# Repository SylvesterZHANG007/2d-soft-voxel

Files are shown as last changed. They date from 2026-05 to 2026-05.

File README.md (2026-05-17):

# 2D Soft Voxel Modular Robot

**[📖 Open Interactive Guide →](https://sylvesterzhang007.github.io/2d-soft-voxel/)**

A 2D soft voxel modular robot system driven by servo motors and gear-rack mechanisms. Each voxel module can actively extend and retract, enabling coordinated multi-module locomotion patterns.

## Repository Structure

```
2d soft voxel/
├── code/                          # Arduino firmware
│   ├── 16_module/                 # 16-servo coordinated sinusoidal motion
│   └── certain_angle/             # Single-servo angle calibration utility
├── hardware model/                # Current SolidWorks design files (v6)
│   ├── soft_voxel_newest version (v6)/   # Latest full voxel assembly
│   ├── battery and board assem/          # Battery housing + servo driver board mount
│   └── cover molding/                    # Cover parts with print-ready STLs
├── print/                         # STL / 3MF files ready for 3D printing (current version)
├── figure and video/              # Photos and demo videos of the hardware
└── previous hardware model (OLD)/ # Design history: v1 → v5 (reference only)
    ├── v2/ … v5/
    └── (loose files)
```

## Hardware

### Key Components
| Component | Description |
|---|---|
| Servo | AGFRC A06CLS V2 (micro coreless servo) |
| PWM Driver | 815 16-Channel Servo Driver (PCA9685-based, I²C address `0x41`) |
| Gear System | Metal gear rack — 20° pressure angle (McMaster-Carr `3757N35`) |
| Microcontroller | Arduino Nano ESP32 |

### 3D Printing (current version — v6)
All print-ready STL/3MF files are in `print/`. Key parts:

| File | Description |
|---|---|
| `entire cover.STL` / `Mirrorentire cover.STL` | Left/right voxel outer covers |
| `gear rack_curve.STL` / `Mirrorgear rack_curve.STL` | Curved gear racks (mirrored pair) |
| `gear rack_curve_offset.STL` / `Mirrorgear rack_curve_offset.STL` | Offset gear racks (mirrored pair) |
| `gear back.STL` | Rear gear support |
| `servo_mount.STL` | Servo mounting bracket |
| `cover_mount.STL` | Cover attachment plate |
| `connector.STL` / `connector1.STL` | Inter-module connectors |
| `battery case.STL` / `battery cover.STL` / `battery switch cover.STL` | Battery enclosure |
| `board support1.STL` | PCB mounting support |
| `switch_v5.STL` | Power switch housing |

### Printing and Casting Materials

| Part Category | Material | Notes |
|---|---|---|
| Module main body (all structural parts) | Bambu Lab PLA Matte — Ivory White | Standard FDM print |
| All gear racks (`gear rack_curve`, `gear rack_curve_offset`, and mirrored variants) | Bambu Lab TPU 95A — Black | Flexible; improves gear mesh compliance and reduces noise |
| Connectors (`connector.STL`, `connector1.STL`) | Bambu Lab PLA — Glow Green | Easy visual identification between modules |
| Cover molding parts (`hardware model/cover molding/`) | Eco-Flex 10 (Smooth-On) | Cast molding — do not 3D print these parts |

**Casting Note:** The cover molding components are designed for silicone casting using Eco-Flex 10. Print the mold halves (`bottom.STL`, `up.STL` in `hardware model/cover molding/print/`) in PLA, mix and pour Eco-Flex 10 per the manufacturer's datasheet, and allow to cure fully before demolding.

### SolidWorks Source Files
`hardware model/soft_voxel_newest version (v6)/` contains the full parametric SolidWorks assembly (`all_assm_1.SLDASM`) and all constituent part files (`.SLDPRT`). Open `all_assm_1.SLDASM` in SolidWorks 2025.

## Software

### Dependencies
- [Adafruit PWM Servo Driver Library](https://github.com/adafruit/Adafruit-PWM-Servo-Driver-Library) — install via Arduino Library Manager

### `code/16_module` — Coordinated 16-Servo Motion
Controls all 16 servos through the PCA9685 driver with a sinusoidal gait:

| Parameter | Value | Description |
|---|---|---|
| `PWM_FREQ` | 333 Hz | Servo PWM frequency |
| `CENTER_ANGLE` | −45° | Center position of oscillation |
| `AMPLITUDE` | 45° | Peak deviation from center |
| `FREQUENCY` | 1.0 Hz | Oscillation frequency |

Each servo has a sign (`servoSign[]`) that determines whether it extends or retracts in phase with the wave, creating a coordinated locomotion pattern across the 4×4 grid of modules.

**Wiring:** Connect PCA9685 to the microcontroller's I²C pins (SDA/SCL). Board address is `0x41`.

### `code/certain_angle` — Single-Servo Calibration
Sets one servo (pin `A3`) to a fixed angle using high-resolution PWM (14-bit, 333 Hz). Useful for calibrating trim and verifying servo range before assembly.

| Parameter | Value |
|---|---|
| `TRIM_US` | 0.0 µs (adjust to correct arm offset) |
| `NEUTRAL_US` | 1520 µs |
| `MIN_US` / `MAX_US` | 500 / 2500 µs |

Open Serial Monitor at 115200 baud to see the computed pulse width for each set angle.

## Design History

Previous hardware iterations are preserved in `previous hardware model (OLD)/` for reference:

| Version | Notes |
|---|---|
| v1–v2 | Early gear-rack concepts |
| v3 | Refined gear geometry; separate servo mount introduced |
| v4 | Alternative gear set with plastic gears; magnet-based connectors explored |
| v5 | Near-final layout; battery + board assembly integrated |
| v6 *(current)* | Streamlined assembly, improved cover molding, mirrored rack geometry |

## Media

`figure and video/` contains reference photos (`extended.jpg`, `shrinked.jpg`) and a demo video (`single module move.MOV`) showing a single voxel extending and retracting.

## Module Calibration and Assembly Guide

This guide outlines the standardized protocol for calibrating the servo motors and assembling the individual modules for the **2d-soft-voxel** robot.

To ensure identical kinematics, predictable behavior, and structural consistency across all modules, you must follow the precise hardware and software separation workflow described below.

---

### Phase 1: Direct Microcontroller Calibration (No PCA9685 Required)

During this initial mechanical alignment and single-module assembly phase, **DO NOT** use the PCA9685 PWM driver board.

The calibration and initial testing of individual module servos must be performed by connecting the servo signal lines **directly** to the designated GPIO pins of the Arduino Nano ESP32.

* **Power Source:** Power the microcontroller solely via the computer's USB port. Do not connect any external power supplies yet.
* **Software Control:** At this stage, exclusively use the `certain_angle` script/function to command and calibrate the servos. Do not attempt to run complex multi-servo coordination codes yet.
* **Why this approach?** This isolates the system to minimal hardware and software dependencies, drastically reducing troubleshooting complexity and preventing configuration or I2C communication errors on the expansion board during structural alignment.

---

### Phase 2: Step-by-Step Calibration and Assembly

#### Step 1: Servo Initial Zeroing
Before integrating any servo motor into a module casing, its spline position must be precisely zeroed to avoid mechanical binding or restricted range of motion post-assembly.
1. Connect the target servo directly to the Arduino Nano ESP32.
2. Run the `certain_angle` script to command the servo to its baseline calibration position (set the target angle to **-90 degrees**).
3. Ensure the servo motor has fully reached, settled, and locked into this position before disconnecting the setup or moving to mechanical installation.

#### Step 2: Reference Deconstruction and Observation
If you are replicating an existing reference module or scaling up production, use a proven module as your visual anchor:
1. Take an existing, correctly operating reference module and carefully disassemble/deconstruct it.
2. Closely observe and document the exact **relative orientation and mounting alignment** between the servo horn (arm) and the servo body at the -90-degree baseline.
3. Note the precise spline tooth engagement to ensure the newly assembled modules do not suffer from a gear-tooth offset.

#### Step 3: Calibrated Module Assembly
With the servo zeroed and the reference alignment understood, proceed to physical fabrication:
1. Mate the new servo horn onto the newly calibrated servo shaft, carefully duplicating the relative angle observed during the reference deconstruction in Step 2.
2. **Ensure Internal Component Consistency**: During final structural fastening, double-check that the relative positions of all internal components and linkages across different modules are completely identical and uniform.
3. Securely tighten all mounting screws while maintaining this alignment to eliminate any mechanical backlash, rotational slop, or structural shifting.

---

### ⚠️ CRITICAL SAFETY WARNING: POWER SEQUENCE

> **STOP:** Do not proceed to full-system testing or connect the high-current battery source until **all individual modules** have been successfully calibrated, assembled, and verified using **ONLY USB power** (via the Arduino Nano ESP32).
>
> Always verify that the system logic, control commands, and individual servo movements function flawlessly under safe USB power limits before connecting the battery. Failure to strictly follow this power sequence can result in permanent damage to the microcontroller and surrounding electronics in the event of an undetected short circuit.

---

## License

This project is released for research and educational use. If you build on this design, a citation or acknowledgment is appreciated.

---

# 2D 软体体素模块化机器人（中文版）

**[📖 打开可视化指导页面 →](https://sylvesterzhang007.github.io/2d-soft-voxel/)**

基于舵机与齿轮齿条机构驱动的 2D 软体体素模块化机器人系统。每个体素模块可主动伸缩，实现多模块协同运动。

## 仓库结构

```
2d soft voxel/
├── code/                          # Arduino 固件
│   ├── 16_module/                 # 16 路舵机协同正弦运动
│   └── certain_angle/             # 单路舵机角度校准工具
├── hardware model/                # 当前 SolidWorks 设计文件（v6）
│   ├── soft_voxel_newest version (v6)/   # 最新完整体素装配体
│   ├── battery and board assem/          # 电池仓 + 舵机驱动板安装座
│   └── cover molding/                    # 外壳零件及可打印 STL
├── print/                         # 当前版本可直接 3D 打印的 STL / 3MF 文件
├── figure and video/              # 硬件照片与演示视频
└── previous hardware model (OLD)/ # 设计历史：v1 → v5（仅供参考）
    ├── v2/ … v5/
    └── （散装文件）
```

## 硬件

### 关键组件
| 组件 | 说明 |
|---|---|
| 舵机 | AGFRC A06CLS V2（微型无铁芯舵机） |
| PWM 驱动板 | 815 16 路舵机驱动器（基于 PCA9685，I²C 地址 `0x41`） |
| 齿轮系统 | 金属齿轮齿条——20° 压力角（McMaster-Carr `3757N35`） |
| 微控制器 | Arduino 兼容板（已测试 Teensy / Arduino Nano） |

### 3D 打印（当前版本——v6）
所有可打印的 STL/3MF 文件均位于 `print/` 目录。主要零件：

| 文件 | 说明 |
|---|---|
| `entire cover.STL` / `Mirrorentire cover.STL` | 体素左/右侧外壳 |
| `gear rack_curve.STL` / `Mirrorgear rack_curve.STL` | 曲线齿条（镜像对） |
| `gear rack_curve_offset.STL` / `Mirrorgear rack_curve_offset.STL` | 偏置曲线齿条（镜像对） |
| `gear back.STL` | 齿轮背板支撑 |
| `servo_mount.STL` | 舵机安装支架 |
| `cover_mount.STL` | 外壳固定板 |
| `connector.STL` / `connector1.STL` | 模块间连接件 |
| `battery case.STL` / `battery cover.STL` / `battery switch cover.STL` | 电池仓组件 |
| `board support1.STL` | PCB 安装支撑 |
| `switch_v5.STL` | 电源开关壳体 |

### 打印与浇筑材料

| 零件类别 | 材料 | 备注 |
|---|---|---|
| 模块主体（所有结构件） | Bambu Lab PLA Matte — 象牙白（Ivory White） | 标准 FDM 打印 |
| 所有齿条（`gear rack_curve`、`gear rack_curve_offset` 及镜像件） | Bambu Lab TPU 95A — 黑色（Black） | 柔性材料；改善齿轮啮合顺应性，降低噪音 |
| 连接件（`connector.STL`、`connector1.STL`） | Bambu Lab PLA — 荧光绿（Glow Green） | 便于各模块之间的视觉识别 |
| 外壳模具零件（`hardware model/cover molding/`） | Eco-Flex 10（Smooth-On） | 浇筑成型——此类零件不得 3D 打印 |

**浇筑说明：** 外壳覆盖层零件设计为使用 Eco-Flex 10 进行硅胶浇筑成型。先用 PLA 打印模具两半（`hardware model/cover molding/print/` 下的 `bottom.STL` 和 `up.STL`），按厂商数据手册混合并浇注 Eco-Flex 10，待其完全固化后再脱模。

### SolidWorks 源文件
`hardware model/soft_voxel_newest version (v6)/` 包含完整的参数化 SolidWorks 装配体（`all_assm_1.SLDASM`）及所有零件文件（`.SLDPRT`）。请使用 SolidWorks 2025 打开 `all_assm_1.SLDASM`。

## 软件

### 依赖库
- [Adafruit PWM Servo Driver Library](https://github.com/adafruit/Adafruit-PWM-Servo-Driver-Library) — 通过 Arduino Library Manager 安装

### `code/16_module` — 16 路舵机协同运动
通过 PCA9685 驱动板以正弦步态控制全部 16 路舵机：

| 参数 | 值 | 说明 |
|---|----|---|
| `PWM_FREQ` | 333 Hz | 舵机 PWM 频率 |
| `CENTER_ANGLE` | −45° | 振荡中心位置 |
| `AMPLITUDE` | 45° | 偏离中心的峰值幅度 |
| `FREQUENCY` | 1.0 Hz | 振荡频率 |

每路舵机有一个符号值（`servoSign[]`），决定其与波形同相伸出还是缩回，从而在 4×4 模块阵列中形成协同运动步态。

**接线：** 将 PCA9685 连接至微控制器的 I²C 引脚（SDA/SCL），板载地址为 `0x41`。

### `code/certain_angle` — 单路舵机校准
使用高分辨率 PWM（14 位，333 Hz）将引脚 `A3` 上的舵机设置到指定角度，用于装配前的行程校准和零位验证。

| 参数 | 值 |
|---|----|
| `TRIM_US` | 0.0 µs（可调整以修正摆臂偏差） |
| `NEUTRAL_US` | 1520 µs |
| `MIN_US` / `MAX_US` | 500 / 2500 µs |

以 115200 波特率打开串口监视器，即可查看每个设定角度对应的脉冲宽度。

## 设计历史

历次硬件迭代均保存在 `previous hardware model (OLD)/` 中，仅供参考：

| 版本 | 说明 |
|---|---|
| v1–v2 | 早期齿轮齿条概念验证 |
| v3 | 齿轮几何优化；引入独立舵机安装座 |
| v4 | 探索塑料齿轮方案；尝试磁性连接件 |
| v5 | 接近最终布局；集成电池与驱动板装配体 |
| v6 *（当前）* | 简化装配、改进外壳模具、采用镜像齿条几何 |

## 媒体资料

`figure and video/` 包含参考照片（`extended.jpg`、`shrinked.jpg`）及演示视频（`single module move.MOV`），展示单个体素模块的伸缩动作。

## 模块校准与装配指南

本指南规定了 **2d-soft-voxel** 机器人舵机校准与单模块装配的标准化流程。

为确保所有模块具备相同的运动学特性、可预测的行为和一致的结构，必须严格遵循以下硬件与软件分离工作流程。

---

### 阶段一：直接通过微控制器校准（无需 PCA9685）

在初始机械对准和单模块装配阶段，**禁止**使用 PCA9685 PWM 驱动板。

单模块舵机的校准与初步测试，必须将舵机信号线**直接**连接至 Arduino Nano ESP32 的指定 GPIO 引脚进行。

* **供电方式：** 仅通过计算机 USB 口为微控制器供电，暂勿接入任何外部电源。
* **软件控制：** 此阶段只使用 `certain_angle` 脚本/函数控制和校准舵机，暂勿运行复杂的多舵机协同代码。
* **原因：** 将系统隔离至最少的硬件和软件依赖，可大幅降低排障复杂度，并防止在结构对准阶段出现扩展板配置错误或 I2C 通信故障。

---

### 阶段二：逐步校准与装配

#### 步骤 1：舵机初始归零
在将舵机装入模块外壳之前，必须精确校准其花键位置，以避免装配后出现机械卡死或运动范围受限。
1. 将目标舵机直接连接至 Arduino Nano ESP32。
2. 运行 `certain_angle` 脚本，将舵机指令至基准校准位置（目标角度设为 **-90 度**）。
3. 确认舵机已完全到达、稳定并锁定在该位置后，再断开连接或进行机械安装。

#### 步骤 2：参考模块拆解与观察
若需复制现有参考模块或批量生产，以一个已验证正常的模块作为视觉基准：
1. 取一个运行正确的参考模块，仔细拆解。
2. 仔细观察并记录舵机摆臂（臂）与舵机本体在 -90 度基准位置时的**相对朝向和安装对准**关系。
3. 注意花键齿的精确啮合位置，确保新装配的模块不出现齿位偏移。

#### 步骤 3：校准后的模块装配
完成舵机归零和参考对准后，进行实物组装：
1. 将新舵机摆臂套入已校准的舵机轴，仔细复现步骤 2 中观察到的相对角度。
2. **确保内部零件一致性：** 最终紧固结构时，逐一核查各模块内部所有零件和连杆的相对位置完全相同、均匀一致。
3. 在保持对准的前提下拧紧所有安装螺钉，消除机械间隙、旋转松旷或结构偏移。

---

### ⚠️ 重要安全警告：供电顺序

> **停止：** 在**所有单模块**均通过 **Arduino Nano ESP32 的 USB 供电**完成校准、装配和验证之前，禁止进行整机测试或连接大电流电池。
>
> 连接电池前，务必先在 USB 安全电流限制下确认系统逻辑、控制指令及单路舵机动作均正常无误。若不严格遵守此供电顺序，一旦存在未发现的短路，将导致微控制器及周边电子元件永久损坏。
>
> *只有当所有的模块在仅仅通过 USB 给 Arduino Nano ESP32 供电调试好之后，才能去连接电池进行下一步。*

---

## 许可证

本项目供研究和教育用途开放使用。若您基于本设计进行二次开发，欢迎注明来源或致谢。

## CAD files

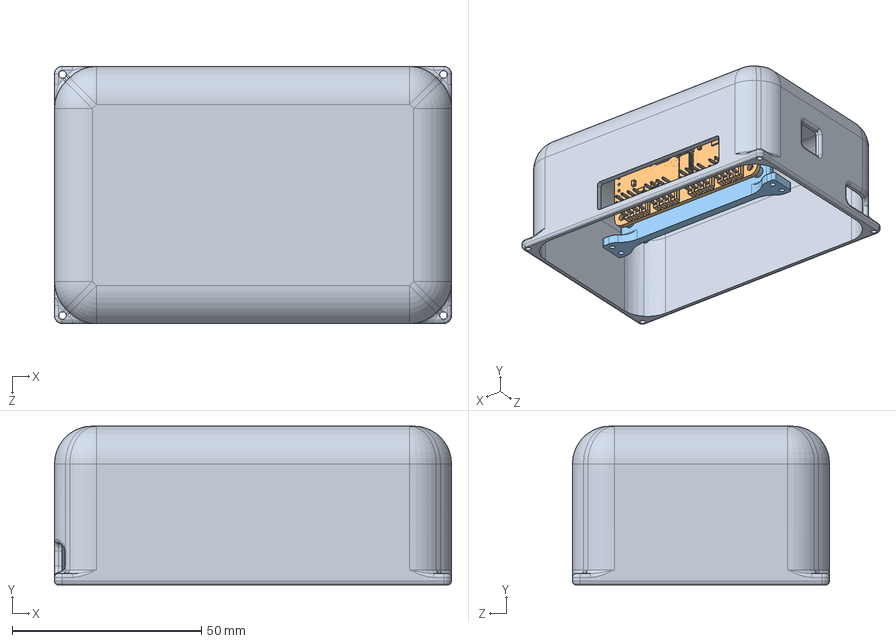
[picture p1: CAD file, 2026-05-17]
hardware model/battery and board assem/battery and board assem.SLDASM
105.0 x 42.0 x 68.0 mm
board support1
815 Servo Driver 16 Channel
battery cover

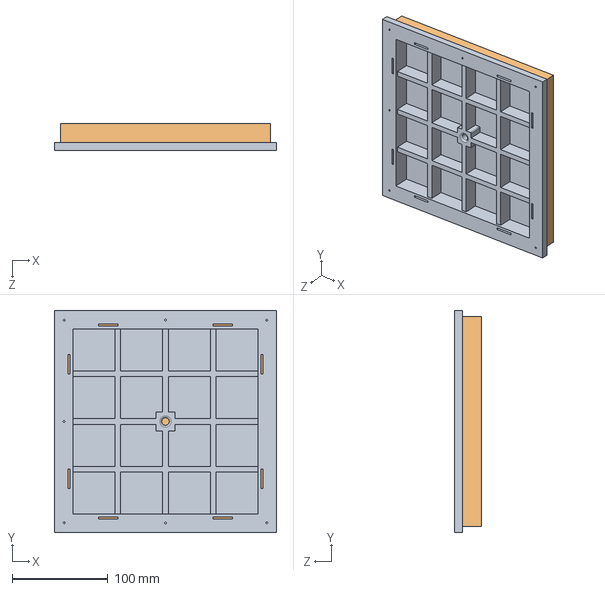
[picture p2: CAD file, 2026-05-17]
hardware model/cover molding/cover.SLDASM
232.2 x 232.2 x 28.0 mm
bottom
up

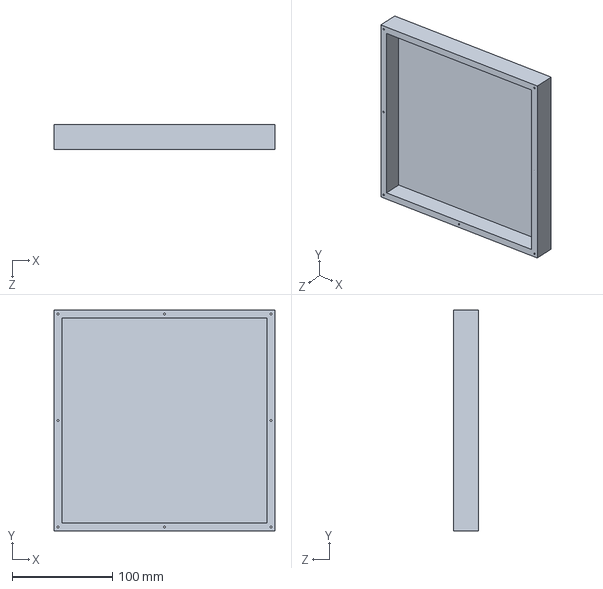
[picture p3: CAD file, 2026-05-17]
hardware model/cover molding/bottom.SLDPRT
220.0 x 220.0 x 25.0 mm

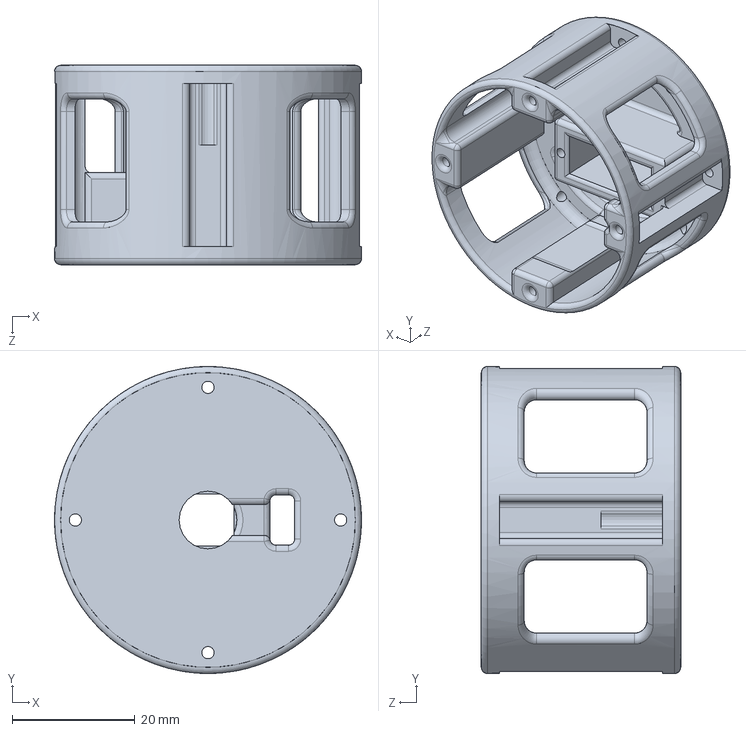
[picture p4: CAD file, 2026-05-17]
hardware model/soft_voxel_newest version (v6)/servo_mount.SLDPRT
50.0 x 50.0 x 32.5 mm

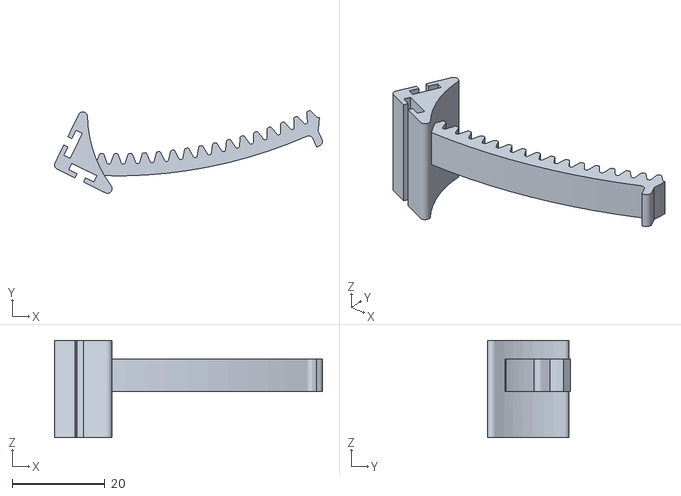
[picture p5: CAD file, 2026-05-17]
print/gear rack_curve.STL
57.8 x 17.8 x 21.0

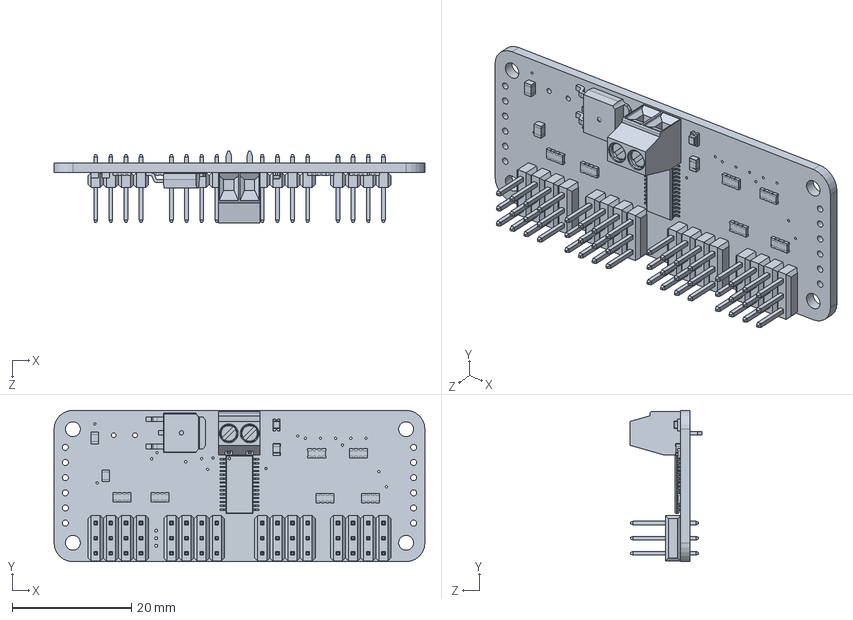
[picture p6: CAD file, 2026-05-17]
hardware model/battery and board assem/815 Servo Driver 16 Channel.SLDPRT
62.2 x 25.4 x 12.1 mm

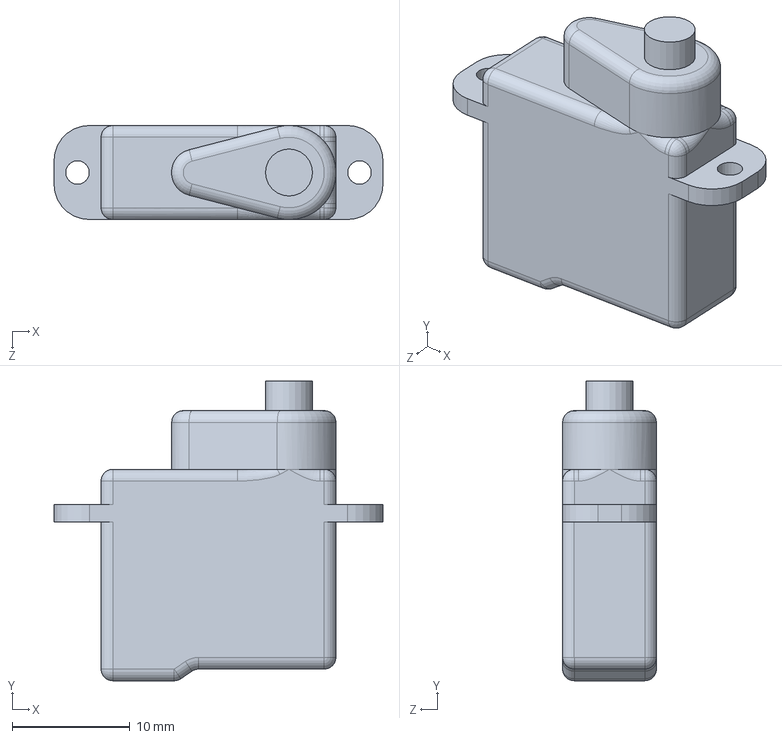
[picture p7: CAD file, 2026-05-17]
hardware model/soft_voxel_newest version (v6)/agfrc a06cls v2.SLDPRT
28.0 x 25.5 x 8.00 mm

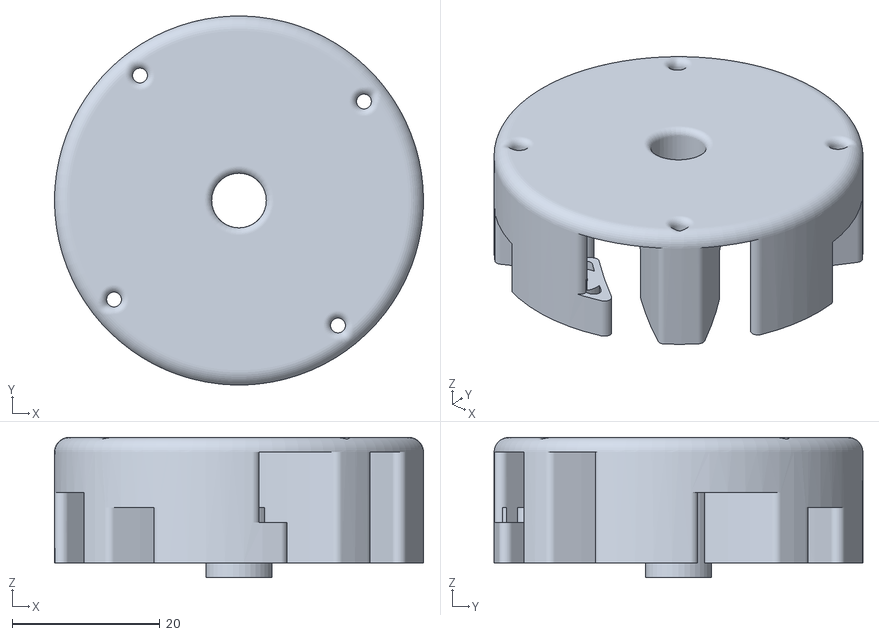
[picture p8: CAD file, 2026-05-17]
print/Mirrorentire cover.STL
50.0 x 50.0 x 19.0

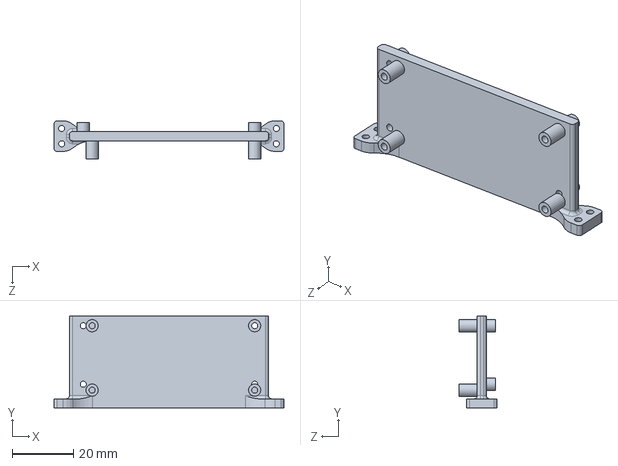
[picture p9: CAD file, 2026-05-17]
hardware model/battery and board assem/board support1.SLDPRT
75.0 x 30.0 x 12.5 mm

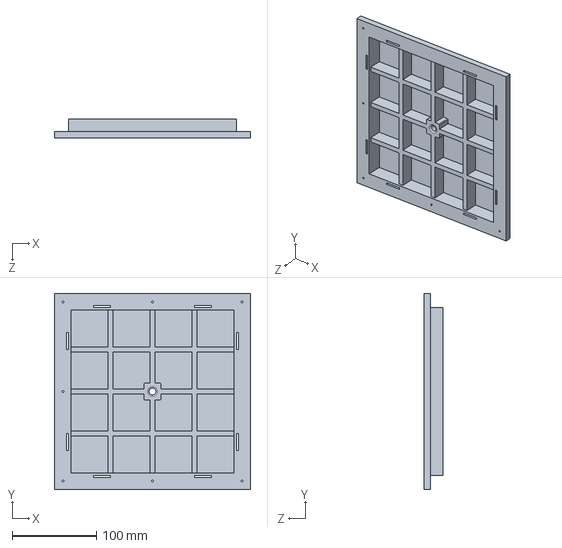
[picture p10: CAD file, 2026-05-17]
hardware model/cover molding/up.SLDPRT
232.2 x 232.2 x 23.0 mm

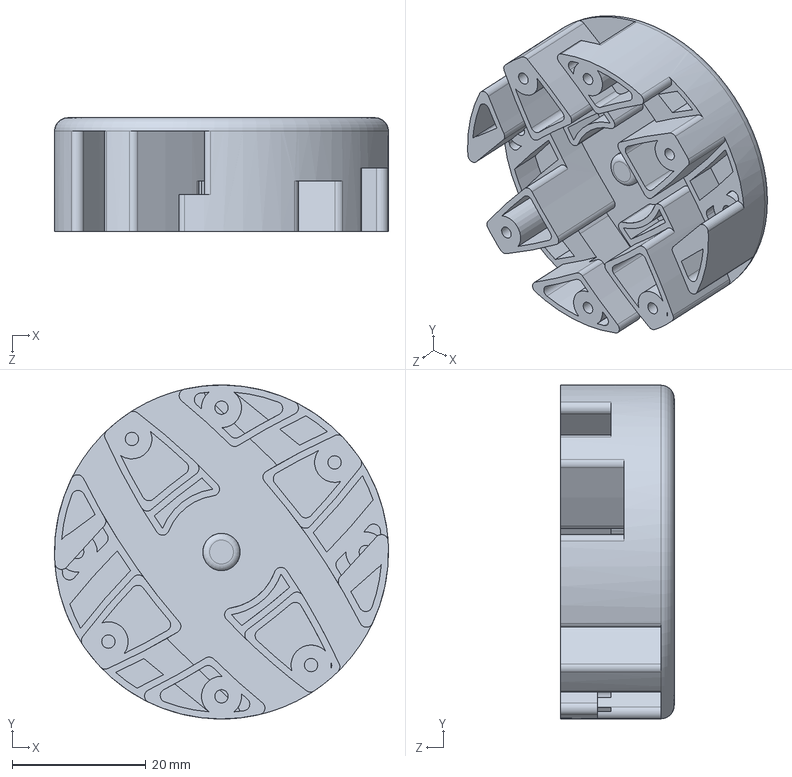
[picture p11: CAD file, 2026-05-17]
hardware model/soft_voxel_newest version (v6)/entire cover.SLDPRT
50.0 x 50.0 x 17.0 mm

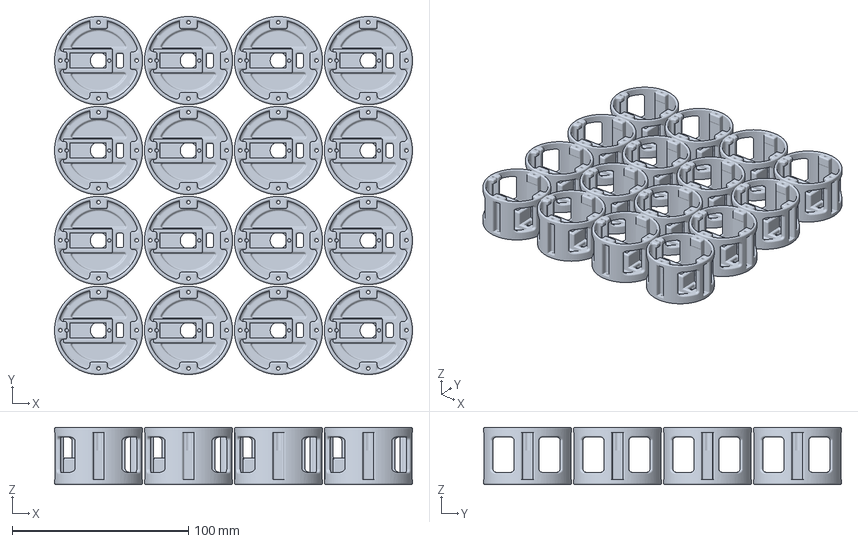
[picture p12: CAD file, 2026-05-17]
print/servo_mount.3mf
203.0 x 203.0 x 32.5 mm

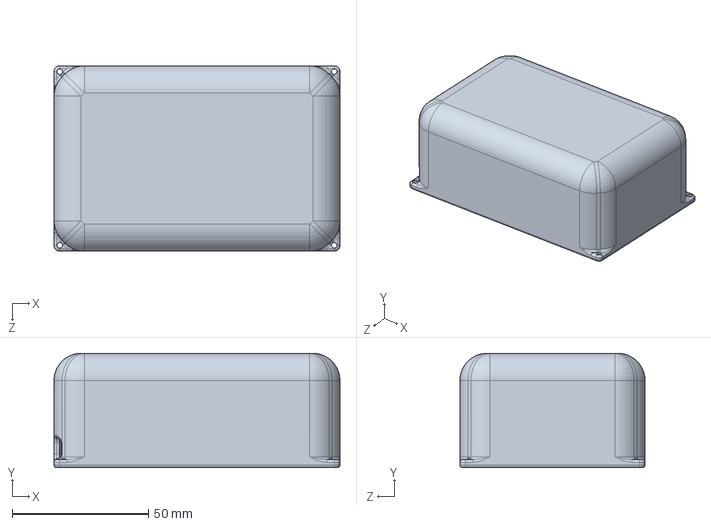
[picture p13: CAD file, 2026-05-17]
hardware model/battery and board assem/battery cover.SLDPRT
105.0 x 42.0 x 68.0 mm

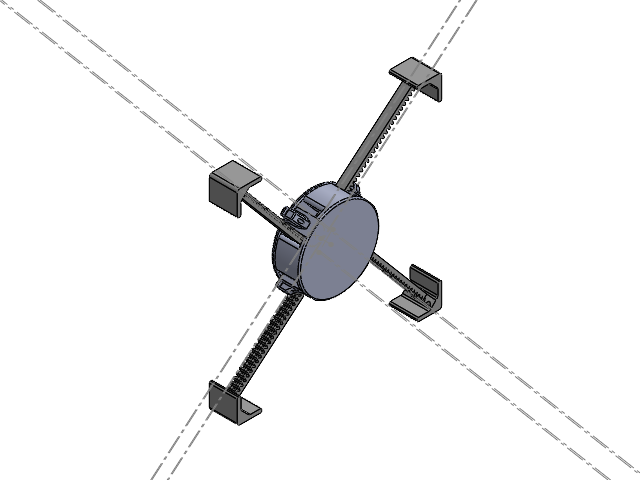
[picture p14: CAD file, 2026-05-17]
hardware model/soft_voxel_newest version (v6)/all_assm_1.SLDASM
3757N35_Metal Gear and Gear Racks-20 Degree Pressure Angle
gear rack x 2
gear supporter
gear cover
gear rack offset x 2
switch

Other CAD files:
hardware model/soft_voxel_newest version (v6)/servo with cross arm.SLDASM
hardware model/soft_voxel_newest version (v6)/soft_voxel_assem_v5_full.SLDASM
hardware model/soft_voxel_newest version (v6)/back_assem_full.SLDASM
hardware model/soft_voxel_newest version (v6)/Mirrorentire cover.SLDPRT
hardware model/battery and board assem/battery case.SLDPRT
hardware model/battery and board assem/battery switch cover.SLDPRT
hardware model/cover molding/print/bottom.STL
hardware model/cover molding/print/up.STL
hardware model/soft_voxel_newest version (v6)/3757N35_Metal Gear and Gear Racks-20 Degree Pressure Angle.SLDPRT
hardware model/soft_voxel_newest version (v6)/Mirrorgear rack_curve.SLDPRT
hardware model/soft_voxel_newest version (v6)/Mirrorgear rack_curve_offset.SLDPRT
hardware model/soft_voxel_newest version (v6)/connector.SLDPRT
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

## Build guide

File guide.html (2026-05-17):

Modular Soft Robotics

模块化软体机器人

# 2D Soft Voxel Modular Robot

A servo-driven gear-rack system where each voxel module actively extends and retracts, enabling coordinated locomotion across a 4×4 module array.

基于舵机与齿轮齿条机构的模块化系统，每个体素模块可主动伸缩，实现 4×4 模块阵列的协同运动。

Arduino Nano ESP32 PCA9685 · 16CH AGFRC A06CLS V2 SolidWorks 2025 Bambu Lab Eco-Flex 10

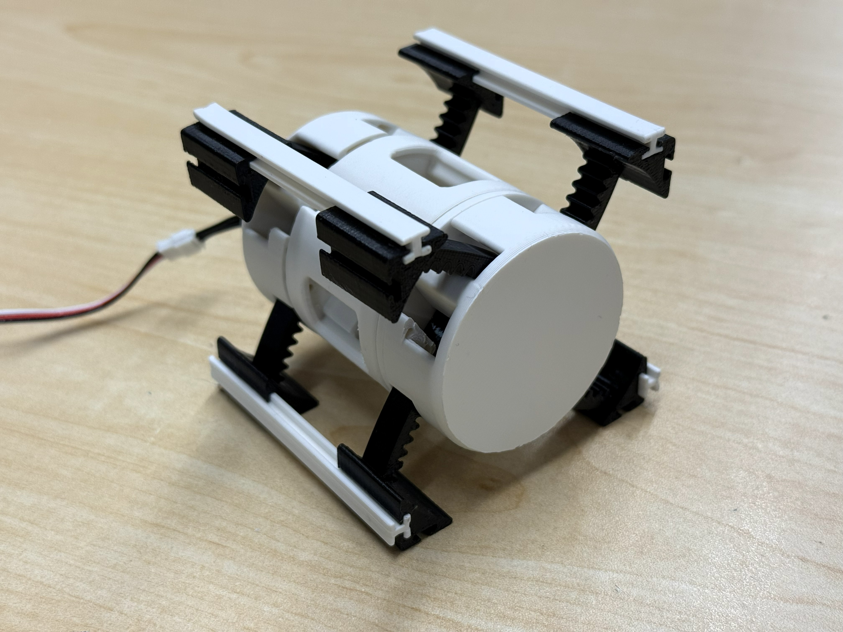
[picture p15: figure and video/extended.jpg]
Module extended


Extended

伸出状态

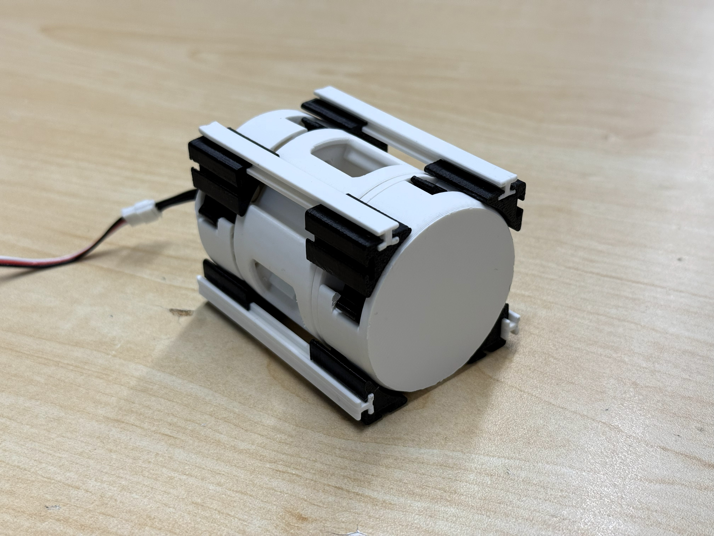
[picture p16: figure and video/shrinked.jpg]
Module retracted


Retracted

收缩状态

Hardware

硬件

## Key Components

## 关键组件

Core electronics and mechanical parts for each voxel module.

每个体素模块的核心电子与机械组件。

⚙️

### Servo Motor

### 舵机

AGFRC A06CLS V2

Micro coreless servo

微型无铁芯舵机

🔌

### PWM Driver

### PWM 驱动板

815 16-Channel Driver
PCA9685 · I²C 0x41

815 16 路舵机驱动器
PCA9685 · I²C 0x41

🦷

### Gear System

### 齿轮系统

Metal rack · 20° PA
McMaster 3757N35

金属齿条 · 20° 压力角
McMaster 3757N35

🧠

### Microcontroller

### 微控制器

Arduino Nano ESP32

🖥️

### CAD Software

### CAD 软件

SolidWorks 2025
Open all_assm_1.SLDASM

SolidWorks 2025
打开 all_assm_1.SLDASM

🖨️

### Printer

### 打印机

Bambu Lab
See materials section below

Bambu Lab
见下方材料章节

Fabrication

制造

## Printing & Casting Materials

## 打印与浇筑材料

Each part category uses a specific material. Do not substitute — material compliance and color coding are intentional.

每类零件使用指定材料，请勿替换——材料的顺应性和颜色编码均为设计所需。

Module Main Body · All Structural Parts

模块主体 · 所有结构件

Bambu Lab PLA Matte
Ivory White象牙白

Standard FDM print. Rigid structural frame for all non-gear, non-connector parts.

标准 FDM 打印。用于所有非齿条、非连接件的刚性结构框架。

All Gear Racks · Curved & Offset Variants

所有齿条 · 曲线及偏置款

Bambu Lab TPU 95A
Black黑色

Flexible. Improves gear mesh compliance and reduces operating noise.

柔性耗材。改善齿轮啮合顺应性，有效降低运行噪音。

Connectors · connector.STL, connector1.STL

连接件 · connector.STL, connector1.STL

Bambu Lab PLA
Glow Green荧光绿

Distinctive color for fast visual identification of inter-module connection points.

醒目颜色，便于快速识别模块间连接点。

Cover Molding · hardware model/cover molding/

外壳模具零件 · hardware model/cover molding/

Eco-Flex 10 (Smooth-On)
Cast Molding Only仅浇筑成型

⚠ Do NOT 3D print these parts. Silicone casting only.

⚠ 此类零件禁止 3D 打印，必须硅胶浇筑成型。

Casting Procedure: 浇筑流程： Print mold halves (bottom.STL + up.STL in hardware model/cover molding/print/) in PLA. Mix Eco-Flex 10 Part A & B per the Smooth-On datasheet, pour into the mold, and cure fully before demolding. 用 PLA 打印模具两半（hardware model/cover molding/print/ 下的 bottom.STL 和 up.STL），按 Smooth-On 数据手册混合 A、B 两组分，浇入模具后待完全固化再脱模。

Firmware

固件

## Software Guide

## 软件说明

Two Arduino sketches — use certain_angle during assembly calibration, 16_module for full operation.

两个 Arduino 程序——装配校准阶段使用 certain_angle，整机运行使用 16_module。

### code/16_module

Controls all 16 servos via PCA9685 with a sinusoidal gait. Each servo's servoSign[] sets its extend/retract phase within the 4×4 array.

通过 PCA9685 以正弦步态控制全部 16 路舵机，每路舵机的 servoSign[] 决定其在 4×4 阵列中的伸缩相位。

Parameter | Value | Description
PWM_FREQ | 333 Hz | Servo PWM frequency
CENTER_ANGLE | −45° | Oscillation center
AMPLITUDE | 45° | Peak deviation
FREQUENCY | 1.0 Hz | Oscillation rate

参数 | 值 | 说明
PWM_FREQ | 333 Hz | 舵机 PWM 频率
CENTER_ANGLE | −45° | 振荡中心位置
AMPLITUDE | 45° | 峰值幅度
FREQUENCY | 1.0 Hz | 振荡频率

Wiring: Connect PCA9685 to SDA/SCL. I²C address: 0x41

接线：将 PCA9685 连接至 SDA/SCL 引脚，I²C 地址：0x41

### code/certain_angle

Sets one servo (pin A3) to a fixed angle via 14-bit PWM at 333 Hz. Use exclusively during assembly calibration — not for multi-servo control.

通过 14 位 PWM（333 Hz）将引脚 A3 上的舵机设置到固定角度。仅用于装配校准阶段，不用于多舵机控制。

Parameter | Value
TRIM_US | 0.0 µs
NEUTRAL_US | 1520 µs
MIN_US | 500 µs
MAX_US | 2500 µs
PWM_RES | 14-bit

参数 | 值
TRIM_US | 0.0 µs
NEUTRAL_US | 1520 µs
MIN_US | 500 µs
MAX_US | 2500 µs
PWM_RES | 14-bit

Open Serial Monitor at 115200 baud to verify computed pulse width for each angle.

以 115200 波特率打开串口监视器，可验证每个角度对应的计算脉冲宽度。

Assembly Guide

装配指南

## Module Calibration & Assembly

## 模块校准与装配

Follow this workflow precisely. Identical kinematics across all modules depend on it.

严格遵循以下流程，所有模块的运动学一致性取决于此。

1

Direct Microcontroller Calibration

直接通过微控制器校准

No PCA9685 required at this stage

此阶段无需使用 PCA9685

- Do NOT use the PCA9685 board. Connect servo signal lines directly to the Arduino Nano ESP32 GPIO pins.
- 禁止使用 PCA9685 驱动板。 将舵机信号线直接连接至 Arduino Nano ESP32 的 GPIO 引脚。
- Power source: USB only. Do not connect any external power supply.
- 供电方式： 仅 USB 供电，暂勿接入任何外部电源。
- Software: Use certain_angle only. Do not run 16_module yet.
- 软件控制： 只运行 certain_angle，暂勿运行 16_module。
- Why? Minimal hardware eliminates I2C errors and PCA9685 configuration issues during mechanical alignment.
- 原因： 最小化硬件依赖，消除机械对准阶段的 I2C 通信错误及扩展板配置问题。

2

Step-by-Step Calibration & Assembly

逐步校准与装配

Repeat all three steps for every module

每个模块均需重复执行以下三步

1

#### Servo Initial Zeroing

#### 舵机初始归零

Zero the servo spline before installing it into the module casing to prevent mechanical binding post-assembly.

在装入模块外壳之前将舵机花键归零，防止装配后出现机械卡死。

1. Connect the servo directly to the Arduino Nano ESP32.
2. Run certain_angle and set the target angle to −90 degrees.
3. Wait until the servo fully settles and locks before proceeding.
1. 将舵机直接连接至 Arduino Nano ESP32。
2. 运行 certain_angle，将目标角度设为 −90 度。
3. 等待舵机完全到达并锁定该位置后，再进行下一步。

2

#### Reference Deconstruction & Observation

#### 参考模块拆解与观察

Use an existing correctly-built module as a visual reference for servo horn alignment.

以一个已验证正常的模块作为摆臂对准的视觉基准。

1. Carefully disassemble the reference module.
2. Document the exact relative orientation of servo horn vs. body at −90°.
3. Note spline tooth engagement to prevent gear-tooth offset in new modules.
1. 仔细拆解参考模块。
2. 记录舵机摆臂与本体在 −90° 时的精确相对朝向。
3. 注意花键齿啮合位置，防止新模块出现齿位偏移。

3

#### Calibrated Module Assembly

#### 校准后的模块装配

With the servo zeroed and reference alignment known, assemble the physical module.

完成舵机归零和参考对准后，进行实物组装。

1. Mount the servo horn, duplicating the reference angle observed in Step 2.
2. Verify internal component consistency — all linkage positions must match across modules.
3. Tighten all screws to eliminate backlash, rotational slop, and structural shifting.
1. 安装舵机摆臂，复现步骤 2 中观察到的参考角度。
2. 核查内部零件一致性——各模块内所有连杆位置必须完全相同。
3. 拧紧所有螺钉，消除机械间隙、旋转松旷和结构偏移。

⚠️ CRITICAL SAFETY WARNING — POWER SEQUENCE 重要安全警告 — 供电顺序

STOP. Do not connect the battery or proceed to full-system testing until all individual modules have been calibrated, assembled, and verified using USB power only.

停止。在所有单模块均已通过 USB 供电完成校准、装配和验证之前，禁止连接电池或进行整机测试。

Verify that all logic, commands, and servo movements function correctly before connecting the battery. An undetected short circuit under battery power may cause permanent damage to the microcontroller and surrounding electronics.

连接电池前，必须确认所有系统逻辑、控制指令及舵机动作均正常。若存在未发现的短路，电池供电时将导致微控制器及周边电子元件永久损坏。

Only after all modules pass USB-powered testing should the battery be connected.

只有当所有的模块在仅仅通过 USB 给 Arduino Nano ESP32 供电调试好之后，才能去连接电池进行下一步。

History

历史

## Design History

## 设计历史

Previous iterations are preserved in previous hardware model (OLD)/ for reference.

历次迭代均保存于 previous hardware model (OLD)/ 中，仅供参考。

v1 – v2

Early gear-rack concepts and initial structural exploration.

早期齿轮齿条概念验证与初始结构探索。

v3

Refined gear geometry; separate servo mount introduced.

齿轮几何优化；引入独立舵机安装座。

v4

Plastic gear set explored; magnet-based connectors tested.

探索塑料齿轮方案；尝试磁性连接件。

v5

Near-final layout; battery and board assembly integrated.

接近最终布局；电池与驱动板装配体集成入模块。

v6 — Current

v6 — 当前版本

Streamlined assembly, improved cover molding, mirrored rack geometry. All source files in hardware model/soft_voxel_newest version (v6)/

简化装配、改进外壳模具、采用镜像齿条几何。源文件位于 hardware model/soft_voxel_newest version (v6)/

Repository

仓库

## Files & Downloads

## 文件与下载

All project files are hosted on GitHub. Click any file to download directly, or browse the full repository.

所有项目文件托管于 GitHub，可直接点击下载，或浏览完整仓库。

View Full Repository on GitHub 在 GitHub 查看完整仓库 (https://github.com/SylvesterZHANG007/2d-soft-voxel)

🖨️ Print Files (STL / 3MF)打印文件 (STL / 3MF) Browse folder → (https://github.com/SylvesterZHANG007/2d-soft-voxel/tree/main/print)浏览文件夹 → (https://github.com/SylvesterZHANG007/2d-soft-voxel/tree/main/print)

- entire cover.STL PLA Ivory↓ STL (https://github.com/SylvesterZHANG007/2d-soft-voxel/raw/main/print/entire%20cover.STL)
- Mirrorentire cover.STL PLA Ivory↓ STL (https://github.com/SylvesterZHANG007/2d-soft-voxel/raw/main/print/Mirrorentire%20cover.STL)
- gear rack_curve.STL TPU Black↓ STL (https://github.com/SylvesterZHANG007/2d-soft-voxel/raw/main/print/gear%20rack_curve.STL)
- Mirrorgear rack_curve.STL TPU Black↓ STL (https://github.com/SylvesterZHANG007/2d-soft-voxel/raw/main/print/Mirrorgear%20rack_curve.STL)
- gear rack_curve_offset.STL TPU Black↓ STL (https://github.com/SylvesterZHANG007/2d-soft-voxel/raw/main/print/gear%20rack_curve_offset.STL)
- Mirrorgear rack_curve_offset.STL TPU Black↓ STL (https://github.com/SylvesterZHANG007/2d-soft-voxel/raw/main/print/Mirrorgear%20rack_curve_offset.STL)
- connector.STL PLA Green↓ STL (https://github.com/SylvesterZHANG007/2d-soft-voxel/raw/main/print/connector.STL)
- connector1.STL PLA Green↓ STL (https://github.com/SylvesterZHANG007/2d-soft-voxel/raw/main/print/connector1.STL)
- servo_mount.STL PLA Ivory↓ STL (https://github.com/SylvesterZHANG007/2d-soft-voxel/raw/main/print/servo_mount.STL)
- servo_mount.3mf PLA Ivory↓ 3MF (https://github.com/SylvesterZHANG007/2d-soft-voxel/raw/main/print/servo_mount.3mf)
- gear back.STL↓ STL (https://github.com/SylvesterZHANG007/2d-soft-voxel/raw/main/print/gear%20back.STL)
- cover_mount.STL↓ STL (https://github.com/SylvesterZHANG007/2d-soft-voxel/raw/main/print/cover_mount.STL)
- battery case.STL↓ STL (https://github.com/SylvesterZHANG007/2d-soft-voxel/raw/main/print/battery%20case.STL)
- battery cover.STL↓ STL (https://github.com/SylvesterZHANG007/2d-soft-voxel/raw/main/print/battery%20cover.STL)
- board support1.STL↓ STL (https://github.com/SylvesterZHANG007/2d-soft-voxel/raw/main/print/board%20support1.STL)
- switch_v5.STL↓ STL (https://github.com/SylvesterZHANG007/2d-soft-voxel/raw/main/print/switch_v5.STL)

🧪 Cover Mold (PLA mold for Eco-Flex casting)外壳模具（PLA 模具用于 Eco-Flex 浇筑）

- bottom.STL mold half模具下半↓ STL (https://github.com/SylvesterZHANG007/2d-soft-voxel/raw/main/hardware%20model/cover%20molding/print/bottom.STL)
- up.STL mold half模具上半↓ STL (https://github.com/SylvesterZHANG007/2d-soft-voxel/raw/main/hardware%20model/cover%20molding/print/up.STL)

💾 Firmware (Arduino)固件 (Arduino) Browse → (https://github.com/SylvesterZHANG007/2d-soft-voxel/tree/main/code)浏览 → (https://github.com/SylvesterZHANG007/2d-soft-voxel/tree/main/code)

- 16_module.ino full array motion全阵列运动↓ .ino (https://github.com/SylvesterZHANG007/2d-soft-voxel/raw/main/code/16_module/16_module.ino)
- certain_angle.ino calibration校准↓ .ino (https://github.com/SylvesterZHANG007/2d-soft-voxel/raw/main/code/certain_angle/certain_angle.ino)

📐 CAD Source (SolidWorks 2025)CAD 源文件 (SolidWorks 2025) Browse → (https://github.com/SylvesterZHANG007/2d-soft-voxel/tree/main/hardware%20model)浏览 → (https://github.com/SylvesterZHANG007/2d-soft-voxel/tree/main/hardware%20model)

- v6 full assembly (SLDASM + all parts) v6 完整装配体（SLDASM + 所有零件） Browse浏览 → (https://github.com/SylvesterZHANG007/2d-soft-voxel/tree/main/hardware%20model/soft_voxel_newest%20version%20(v6))

2D Soft Voxel Modular Robot · GitHub Repository (https://github.com/SylvesterZHANG007/2d-soft-voxel) · Released for research and educational use.

2D 软体体素模块化机器人 · GitHub 仓库 (https://github.com/SylvesterZHANG007/2d-soft-voxel) · 供研究和教育用途开放使用。

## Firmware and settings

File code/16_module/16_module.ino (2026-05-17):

#include <Wire.h>
#include <Adafruit_PWMServoDriver.h>

Adafruit_PWMServoDriver pwm = Adafruit_PWMServoDriver(0x41);

#define PWM_FREQ    333
#define SERVO_MIN   682
#define SERVO_MAX   3412
#define NUM_SERVOS  16

int servoAngles[NUM_SERVOS] = {0};

#define CENTER_ANGLE  -45.0
#define AMPLITUDE      45.0
#define FREQUENCY       1.0

const int8_t servoSign[NUM_SERVOS] = {
   1,  1,  -1,  -1,
  1, 1, -1, -1,
   -1,  -1,  1,  1,
  -1, -1, 1, 1
};

bool initialized = false;
unsigned long startTime = 0;

uint16_t angleToPulse(int angle) {
  return map(angle, -90, 90, SERVO_MIN, SERVO_MAX);
}

void setServo(uint8_t channel, int angle) {
  angle = constrain(angle, -90, 90);
  servoAngles[channel] = angle;
  pwm.setPWM(channel, 0, angleToPulse(angle));
}

void setup() {
  pwm.begin();
  pwm.setOscillatorFrequency(27000000);
  pwm.setPWMFreq(PWM_FREQ);
  delay(10);

  for (uint8_t i = 0; i < NUM_SERVOS; i++) {
    setServo(i, -45);
  }

  delay(2000);  // hold -45° for 2 seconds right here

  startTime = millis();
}

void loop() {
  float t = (millis() - startTime) / 1000.0;
  float wave = sin(2.0 * PI * FREQUENCY * t);

  for (uint8_t i = 0; i < NUM_SERVOS; i++) {
    float angle = CENTER_ANGLE + AMPLITUDE * servoSign[i] * wave;
    setServo(i, (int)angle);
  }

  delay(3);
}

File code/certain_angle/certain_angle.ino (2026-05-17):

// —— 规格参数 ——
const int SERVO_PIN    = A3;
const int PWM_FREQ     = 333;
const int PWM_RES_BITS = 14;

// —— 微调参数 ——
// 25T摆臂半个齿 ≈ 7.2°，对应约78µs
// 摆臂偏右用负值，偏左用正值，根据实际微调
float TRIM_US = 0.0;

// —— 由规格算出的常量 ——
const int   NEUTRAL_US = 1520;
const int   MIN_US     = 500;
const int   MAX_US     = 2500;
const int   SPAN_POS   = MAX_US - NEUTRAL_US;   // 980
const int   SPAN_NEG   = NEUTRAL_US - MIN_US;   // 1020
const long  PERIOD_US  = 1000000L / PWM_FREQ;   // 3003
const uint32_t MAX_DUTY = (1UL << PWM_RES_BITS) - 1; // 16383

// —— 校准后的中位脉宽 ——
const float CALIBRATED_NEUTRAL_US = NEUTRAL_US + TRIM_US;

void setup() {
  Serial.begin(115200);
  while (!Serial);

  analogWriteResolution(PWM_RES_BITS);
  analogWriteFrequency(PWM_FREQ);

  // 归位到 0°
  writeServoCentered(-90);
}

void loop() {
  // 保持不动
}

void writeServoCentered(int angle) {
  // 限幅到 [-90, +90]
  int a = constrain(angle, -90, +90);

  // 计算脉宽（µs）
  float pulse_us;
  if (a >= 0) {
    pulse_us = CALIBRATED_NEUTRAL_US + (SPAN_POS * a) / 90.0;
  } else {
    pulse_us = CALIBRATED_NEUTRAL_US + (SPAN_NEG * a) / 90.0;
  }

  // 安全限幅
  if (pulse_us < MIN_US) pulse_us = MIN_US;
  if (pulse_us > MAX_US) pulse_us = MAX_US;

  Serial.print("Set Angle: ");
  Serial.print(a);
  Serial.print("°, Pulse: ");
  Serial.print(pulse_us, 1);
  Serial.println(" µs");

  // 脉宽 → 占空比
  uint32_t duty = (uint32_t)((pulse_us * (float)MAX_DUTY + PERIOD_US / 2.0) / PERIOD_US);

  // 输出 PWM
  analogWrite(SERVO_PIN, duty);
}

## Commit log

2026-05-17 Initial commit: 2D soft voxel modular robot project
    Includes Arduino firmware, SolidWorks hardware models (v6 current + v1-v5 history),
    print-ready STL/3MF files, demo media, and README documentation.
    [1module-v2.SLDASM, 1module.SLDASM, 2-5 test.STL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]
2026-05-17 docs: add Module Calibration and Assembly Guide to README
2026-05-17 docs: fix English-only section, update MCU to Arduino Nano ESP32, SolidWorks to 2025
2026-05-17 docs: add printing and casting materials guide (EN + ZH)
2026-05-17 fix: ensure strict language separation in guide (CSS, material names, warning box)
